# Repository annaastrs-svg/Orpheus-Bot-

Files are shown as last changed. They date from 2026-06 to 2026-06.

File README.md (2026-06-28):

STARPHEUS BOT
----
good pic boro

giño
starpheis

https://annaastrs-svg.github.io/STARPHEUS-PAG/
Take a look to the web page !

[also my build journal :P](journal.md)

Orpheus Bot It's a robot inspired by the Hack Club mascot (Orpheus).
Starpheus is a Wall-E type robot.
You can control it with a LogiTECH controller (you control its neck with an MG996R servo motor and the TT motors). 
It has 3 OLEDs that make up its eyes and mouth, simulates emotions with basic state machines (scared, happy, sleepy, neutral),
and uses an HC ultrasonic sensor to avoid collisions.
NOTE: this is a rlly full demo jsjjs 

Design
-------
The complete BOT is 31 cm tall, and 31 cm long counting the arms, its designed to look cool (idk if it is,for me it is), i wanted it to be like a Walle-E type.

Captura de pantalla 2026-06-25 231214
The design was made so that our little Starpheus isn't heavy and has good mobility.

It has details to be able to put our components and hollow parts so that the chassis isn't heavy and has more mobility, as I already mentioned.

details:

holes for 3 OLED screens (2x 0.96 & 0.91 )
a reset button at the back
the ESP32-S3 connector at the back
the ultrasonic sensor in the front
and spots to attach the motors.

I'm an amateur, this is my biggest solo project so far, and I like to challenge myself.
Honestly, I struggled a lot with this project. I changed everything from one moment to the next thousands of times. It was going to have computer vision and an infrared sensor so you could pet it, it was going to be semi-autonomous, but it was very ambitious. This is the beginning of Starpheus; in the future, I’ll improve it and all these ideas will be more than just ideas. 

dormido muerto
back

PCB
---
esquema

esq

Captura de pantalla 2026-06-24 214031

CAD
---
Captura de pantalla 2026-06-25 231259
Captura de pantalla 2026-06-25 225029
Captura de pantalla 2026-06-25 231134

I made this EXCEL with all the connections :B

Videos
---
sorry about the quality and my room mess...

https://github.com/user-attachments/assets/39a8d48d-7ff0-484d-94e4-6cae62331124

https://github.com/user-attachments/assets/a8ff2db2-2984-4ae0-9904-147b8f435752

BOM 
--
| Component | Description | Unit | Cost | Distibutor | Link |
|---|---|---|---|---|---|
| ESP32-S3 | Micro Controler, send code to components | 1 | $34.91  | AlliExpress | https://es.aliexpress.com/item/1005009212121307.html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  |
| DRV8833 | H bridge for motors and control PWM | 1 | $2.50 | AlliExpress | https://es.aliexpress.com/item/1005006151344347.html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 |
| OLED.96 | Display, shows data (orpheus eyes) | 2 | $4.49 | Mercado Libre | https://articulo.mercadolibre.com.mx/MLM-705156753-display-pantalla-oled-128x64-096-para-arduino-_JM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 |
| OLED.91 | Display, shows data (orpheus mouth) | 1 | $1.31 | MercadoLibre |https://www.mercadolibre.com.mx/pantalla-oled-azul-128x32-i2c-091/p/MLM2068167145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  |
| HC-SR04 | Ultra sonic sensor, meausres distance | 1 | $2.96 | Mercado Libre |https://www.mercadolibre.com.mx/sensor-de-distancia-hc-sr04-ultrasonico/p/MLM2039690988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 |
| MG-996R | Servo Motor, orpheus neck | 1 | $7.33 | Amazon | https://www.amazon.com.mx/MG996R-55G-servomotor-Helic%C3%B3ptero-Arduino/dp/B0D7M2Y2BR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 |
| tt engines | Movement or orpheus bot | 2 | $4.00 | AlliExpress | https://es.aliexpress.com/item/1005010779121177.html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 |
| buck converters | For Voltage Protecction of the components  | 3 | $6.76 | Amazon |  https://www.amazon.com.mx/Converter-Aumento-Ajustable-Reguladora-Conector/dp/B09Q8YTQXB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 |
| Resistors 1k | Kit of resistores, It helps with voltages  | 3 | $1.67 | Amazon |https://www.amazon.com.mx/Resistencias-Metal-Film-Resistencia-Electr%C3%B3nicos/dp/B0CT529YD5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 |
| Capacitores 470uf | Kit of Capacitores, It helps with voltages | 3 | $1.21 | AlliExpress | https://es.aliexpress.com/item/1005006079381755.html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 |
| Potobard | Helps With the wiring | 1 | $3.41 | Amazon | https://www.amazon.com.mx/Protoboard-MB-102-Prototipo-soldadura-unidades/dp/B08BCLRLTQ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 |
| Wires Dupont | Kit, Conects the components | 1 | $1.79 | Amazon | https://www.amazon.com.mx/Cables-Pruebas-Opcionales-Surtido-Multicolor/dp/B0DKD315BQ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 |
| Push Botton | I added for a RST button of ESP32 () | 1 | $3.35 | Ebay | https://www.ebay.com/itm/376667835321?itemid=376667835321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 |

There are a lot of components, it's a bit tedious but worth it. I will implement an ESP32 Cam in the future and they cost 3 bucks because I have a spare one. I recommend buying lots of batteries!!

ASSEMBLY 
---

| Orpheus Connections | | | | | | | | | | | |
|---|---|---|---|---|---|---|---|---|---|---|---|
| Come From | | Goes To | | | | Come From | | Goes To | | Goes To | |
| Component | Pin | Component | Pin | | | Component | Pin | Component | Pin | Component | Pin |
| ESP32 S3 | 9 | OLED 1 | SCK | | | Buck 2 | out + | Capacitor 470uf | Positive +  | MG996R | 5V |
| ESP32 S3 | 8 | OLED 1 | SDA | | | | | Capacitor 470uf | Negative -  | Protoboard 1 | Negative |
| ESP32 S3 | 14 | MG996R | S | | | Buck 2 | out - | Protoboard1 | Negative -  | | |
| ESP32 S3 | 10 | OLED 2 | SDA | | | Buck 2 | in + | Protoboard 2 | Positive +  | | |
| ESP32 S3 | 11 | OLED 2 | SCK | | | Buck 2 | in - | Protoboard1 | Negative -  | | |
| ESP32 S3 | 38 | OLED 3 | SDA | | | | | | | | |
| ESP32 S3 | 39 | OLED 3 | SCK | | | Buck 1 | out + | Capacitor 470uf | Positive +  | DRV8833 | 5V |
| ESP32 S3 | 15 | DRV8833 | IN1 | A | | | | Capacitor 470uf | Negative -  | Protoboard 1 | Negative |
| ESP32 S3 | 16 | DRV8833 | IN2 | A | | Buck 1 | out - | Protoboard 1 | Negative | | |
| ESP32 S3 | 17 | DRV8833 | IN3 | B | | Buck 1 | in + | Protoboard 2 | Positive +  | | |
| ESP32 S3 | 18 | DRV8833 | IN4 | B | | Buck 1 | in- | Protoboard 1 | Negative -  | | |
| ESP32 S3 | 5 | HC-SR04 | TRIG | | | | | | | | |
| ESP32 S3 | 6 | R1 (1kohm) | ECHO | R2 (2kohm) | | BATTERY | OUT + | Protoboard 2 | Positive +  | | |
| MG996R | GND | Protoboard 1 | Negative - | | | BATTERY | OUT - | Protoboard 1 | Negative -  | | |
| OLED 0.96  (1 & 2)  | GND | Protoboard 1 | Negative - | | | | | | | | |
| OLED 0.96  (1 & 2)  | 5V | Protoboard 1 | Positive + | | | | | | | | |
| OLED 0.91 | GND | Protoboard 1 | Negative - | | | | | | | | |
| OLED 0.91 | 5V | Protoboard 1 | Positive + | | | | | | | | |
| HC-SR04 | GND | Protoboard 1 | Negative - | | | | | | | | |
| DRV8833 | GND | Protoboard 1 | Negative - | | | | | | | | |
| DRV8833 | OUT1 | MOTOR A | NO POLARIDAD | | | | | | | | |
| DRV8833 | OUT2 | MOTOR A | NO POLARIDAD | | | | | | | | |
| DRV8833 | OUT3 | MOTOR B | NO POLARIDAD | | | | | | | | |
| DRV8833 | OUT4 | MOTOR B | NO POLARIDAD | | | | | | | | |
| | | | | | | | | | | | |
| | | | | | | | | | | | |
| | | | | | | | | | | | |
| | | | | | | | | | | | |
| | | | | | | | | | | | |
| | | | | | | | | | | | |
| | | | | | | | | | | | |

Wiring Little Tutorial, Moustly Explication
----

To build this, there are several things you need to take into account. 
First, the common GND that I implemented with my trusted protoboard: absolutely all the GNDs go to the negative of the protoboard. In the wiring table I made, it's the negative of protoboard 1.
I have divided my protoboard into two sections: the common GND and the 5V for the ESP, the OLEDs, and the ultrasonic sensor,
The second part is for connecting the battery directly and the IN+ of the buck converters, Why don't they go with the other components and get excluded? That's because if we put them together, we’ll damage the components, and that wouldn’t be good. Make sure everything is connected well because sometimes things get loose on the protoboard.  

It’s very logical; you need to make sure the circuit closes properly so it works, and what killed me the most in this project were the voltages, The recommended battery is 7.4V, but after 2 hours of testing it runs out. You can use 6 AA batteries in series or do what I did,I made a long cable by stripping one I had and adapted it to connect to Starpheus. It's like it has a strap, but it's really useful and functional if you're poor like me and can't be buying batteries every 3 hours.

Use 2 capacitors and 3 resistors, 1 capacitor of 470uF for the out+ of the two buck converters (motor and servomotor) so they don't cause power spikes. The resistors are for the ultrasonic sensor. I put a 1k resistor on the wire going from pin 5 of the ESP32S3 to the breadboard; one leg touches that wire directly and the other goes to another wire that goes to the echo of the HCSR04. On that same pin, I directly put two 1k resistors in series to make 2k, and the other leg goes to GND. This is so that the HCSR04 doesn't make too much noise since it's at 5V along with the OLEDs and the ESP32S3.  

Since we have many components drawing a lot of current, we have to consider the motors. In the math part, you need to know a bit about static friction and kinetic friction. Kinetic friction has to be greater than static friction because generally the coefficient of static friction is always higher than the kinetic one, so the motor force has to be greater than the maximum static friction force.
wires

LICENSE
---
MIT

PS:(sorry for some gramatic errors and bad spelling, enlish is not my best lenguage)
thank you a lot hack club staff and people looking at this <3

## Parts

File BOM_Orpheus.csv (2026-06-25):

Component | Description | Unit | Cost | Distibutor | Link
ESP32-S3 | Micro Controler, send code to components | 1 | $34.91 | Amazon | LIANXUE Potente ESP32S3-DevKitC-1 Placa de desarrollo WiFi Microcontrolador Procesador ESP32S3-WROOM-1-N16R8 Placa de desarrollo de repuesto : Amazon.com.mx: Electrónicos
DRV8833 | H bridge for motors and control PWM | 1 | $111.00 | Amazon | EC Buying DRV8833 - Módulo de driver de motor de doble puente H compatible con TB6612FNG PCB rojo : Amazon.com.mx: Herramientas y Mejoras del Hogar
OLED.96 | Display, shows data (orpheus eyes) | 2 | $4.49 | Mercado Libre | https://articulo.mercadolibre.com.mx/MLM-705156753-display-pantalla-oled-128x64-096-para-arduino-_JM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
OLED.91 | Display, shows data (orpheus mouth) | 1 | $1.31 | AlliExpress | Módulo OLED de 0,91 pulgadas 0,91 "Blanco Azul 128X32 Pantalla LED LCD 0,91" IIC Comunicar para Arduino - AliExpress 502
HC-SR04 | Ultra sonic sensor, meausres distance | 1 | $2.96 | Mercado Libre | Sensor De Distancia Hc-sr04 Ultrasónico | Meses sin interés
IR | infrared sensor, orpheus detects touch | 1 | $4.88 | AlliExpress | Módulo de Sensor Infrarrojo IR para Evitar Obstáculos, para Arduino, Coche Inteligente, Robot, Fotoeléctrico Reflectante de 3 Cables, Nuevo
MG-996R | Servo Motor, orpheus neck | 1 | $7.33 | Mercado Libre | Servomotor Mg996r / Mg995 Servo Motor | Envío gratis
dc engines | Movement or orpheus bot | 2 | $4.00 | AlliExpress | Motorreductor TT 1:48 3 a 6 V DC 200 RPM : Amazon.com.mx: Deportes y Aire Libre
buck converters | For Voltage Protecction of the components | 3 | $6.76 | AlliExpress | Regulador de Voltaje LM2596 Buck Converter 3-40V a 1.5-35V 3A : Amazon.com.mx: Electrónicos
Resistors 1k | Kit of resistores, It helps with voltages | 3 | $1.67 | AlliExpress | 100 piezas de resistores de película metálica de 1/4W, 1R ~ 1M ohmios, 100R, 220R, 330R, 1K, 1.5K, 2.2K, 3.3K, 4.7K, 10K, 22K, 47K, 100K, 100, 220, 330, 1K5, 2K2, 3K3, 4K7
Capacitores 470uf | Kit of Capacitores, It helps with voltages | 3 | $1.21 | AlliExpress | 5 uds 35V 470uF condensador electrolítico de aluminio 4V 10V 16V 25V 35V 100UF 220UF 330UF 470UF 680UF 1000UF 47UF 1500UF 10UF 22UF - AliExpress 502
Potobard | Helps With the wiring | 1 | $3.41 | AlliExpress | Destec Protoboard MB-102, 830 Puntos de Conexión, Placa de Pruebas Electrónicas : Amazon.com.mx: Industria, Empresas y Ciencia
Wires Dupont | Kit, Conects the components | 1 | $1.79 | AlliExpress | Cable Dupont macho a macho, 10CM, 40 piezas, fila de 2,54 MM, Cable de puente de placa de pruebas para cables eléctricos Arduino - AliExpress 13
Push Botton | I added for a RST button of ESP32 () | 1 | $3.35 | Mercado Libre | Switch De Push, De Boton Redondo, Normalmente Abier | Au-105 Rojo | Envío gratis

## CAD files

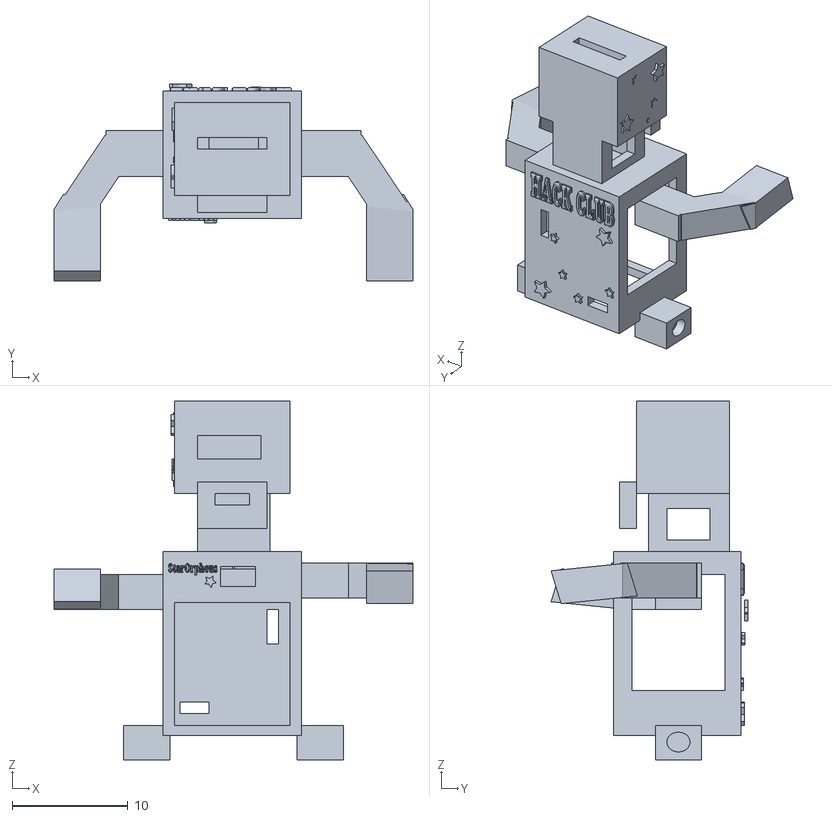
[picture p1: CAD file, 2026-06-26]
STARPHEUS.stl
31.0 x 17.0 x 31.0

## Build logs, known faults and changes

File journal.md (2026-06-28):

A Walle-Etype companion robot inpired by Orpheus, the Hack Club mascot.
face, emotions, ultrasonic sensing and Logitech control.

STARPHEUS 
----
Anna Strs (annaastrs-svg)

2026-06-01

STARPHEUS JOURNAL !
---

starpheus bot is a robot inpired by orpheus, you can controll it, but he reacts to his enviroment with his face made by 3 OLEDS (1 per eye and 1 for mouth).

total time spent so far: ~70 hrs

THE IDEA
---

i love to build cute things that have its own "life" starpheus is interactive and has mobility. 
I dont remember exactly how or why i thought about orpheus.
The complete plan with starpheus was: computer vision, autonomus, curious and infrared sensors. 

STARPHEUS first sketch:

Captura de pantalla 2026-06-20 233143

The emotional Face
----

first thing i built was the face, two oleds were the start, one for mouth and other one for eyes, (I changed it cus it was too small)
the first state machine for emotions : neutral, sleepy, angry, heart face.

the challenge of this came after, the oleds share the same I2C adress (0x3C) so they fight if you put thwm on the same bus. i had to separate I2C buses. 
cara dormido
asustado medio cuerpo

The neck servomotor
----

the mg9963 for the neck gave me SO much touble. It wouldnt move with low current, some thimes he dont even move...
i learned after 2 hours that:
it needs enough current 
it needs a capacitor 470uf or it browns out
loose wires ruin evrything....

The worst decision of my life (ESP32 CAM)
----

the idea of starpheus was to SEE YOU. computer vision was the goal. 
but it nnever worked at any point, because the camera I got was  CLONE, and it didnt work with any library,
I really tryed SO MUCH 😿 
in the end i made a hard decision. drop the camera and ude a ultrasonic sensor to detect presence instead.
the computer vision idea STAYS for future improvement.
Captura de pantalla 2026-06-19 173344
the camera detected the face position in Y and X nut never send the info to my ESP32S3  

PCB!!
--
I designed a costum PCB in KiCAD, to make conecctions cleaner instead of the mess i have, unfortunetly i dont have the money for buying it...

Captura de pantalla 2026-06-24 195610
esquema
Captura de pantalla 2026-06-24 214031

The body CAD 3D
----
I designed the chassis, a complete bot 31 cm tall and 31 cm long counting the arms. 
it have a lot of details and is thinked for it to dont being heavy, so the movement can be better.
Captura de pantalla 2026-06-25 231259
Captura de pantalla 2026-06-25 231148
Captura de pantalla 2026-06-25 231214

have details so u can put ur ESP32S3
a botton for RST the esp32s3 
the oled holes
ultrasonic hole
and to attach the motors.

Power struggles
----
The power was the thing that killed me the most.
the recommend batterry is 7.4V 2S LiPo but i cant afford it lol
and i learned that 9V battery DONT WORK OUT they give voltage but they dont give enough current
so that makes the motors drown it.

I made my own stripping one, I had and adapted it so Starpheus can run from a wall, its like it has a strap but is really usefull and functional if u are poor just like me.
you can also use a 6AA baterries in series, I tryed but i think i did it wrong cus they started overheating
REMEMBER this is a really worked out demo so eventually ill add a 7.4V battery.

Putting it all together
-----
I made a excel with all the wires you need to make.
Captura de pantalla 2026-06-24 170230
Honestly i struggled a lot with this, my head still hurts thinking about this...

What I learned 
---

I learned a lot with this project. 
sometimes u dont notices evrything has to do with math, the friction maths for the motor are soo cool 
its hard sometimes cus you dont know were to start or ypu are scared of trying and not making it "that good" 
but i guess we all start somewhere, u just need to dont make it with fear 

Future improvements
---
COMPUTER VISION! with a no clone camarra that actually follows ur face with the neck.
a proper battery...
audio and sound expressions 
a more complete control app

Photos i like about starpheus construction
---
post fin
idel
 my sister telled me his name is "star-feo" feo means in spainsh ugly ...

 tired lol

sleppy 

Captura de pantalla 2026-06-26 234659
Controll pag !
Captura de pantalla 2026-06-26 234435

i was so happy 

Captura de pantalla 2026-06-25 225412

AJJSSJSJS HE LOOKS SO TIRED

Captura de pantalla 2026-06-25 225356

I tried making a serie of AA batterys but i lit burn my finger, still hurts...a lot 

Captura de pantalla 2026-06-22 215209

PS:Thanks u all for looking at these im rlly greatfull <3
